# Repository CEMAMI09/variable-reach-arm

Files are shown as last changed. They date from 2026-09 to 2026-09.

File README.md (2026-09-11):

# Variable-Reach Dynamic Catching Arm

Stationary **3-DOF** manipulator with a **telescoping boom** that changes reach during interception of lightweight foam balls.

> **Engineering review B (2026-09-07): NOT a manufacturing or powered-motion release.**
> The end effector is a **three-finger grabber; no net**. The original CAD, STL files,
> motor claims and $449 budget were conceptual and are superseded where noted below.
> Complete-machine ordering remains blocked. Firmware intentionally cannot arm until
> real drivers, feedback, homing and independent stop hardware are qualified.

Current review entry points:

- `engineering/sizing.py` and `engineering/design_parameters.json`: current SI model.
- `cad/scripts/build_review_telescope.py` and `claw_gripper.py`: current parametric study.
- `cad/review_b/`: actual FreeCAD studies, geometry checks and **unpowered fit-only** STLs.
- `docs/embedded_protocol.md`: matching v2 host/MCU protocol; replaces the old v1 layout.
- `docs/review_progress.md`: accepted user corrections and review continuity.
- `docs/safety.md` and `cad/drawings/print_guide.md`: current release restrictions.

Legacy `cad/freecad/VariableReachArm.FCStd`, `cad/stl/`, old STEP and animations are
retained as historical design evidence. Do not manufacture or infer physical performance
from them. A valid CAD solid and a successful animation do not establish load paths,
assembly feasibility, motor capacity or capture success.

## Quick start

```bash
# Engineering calculations
python3 engineering/sizing.py

# Host simulation (no hardware)
python3 -m simulation.run_demo

# Plot a telemetry CSV
python3 tools/plot_run.py data/experiments/example_run.csv
```

## Docs

| Doc | Content |
|-----|---|
| [docs/requirements.md](docs/requirements.md) | Spec-derived requirements |
| [docs/architecture.md](docs/architecture.md) | Subsystems & protocol |
| [docs/safety.md](docs/safety.md) | Safety rules |
| [docs/calibration.md](docs/calibration.md) | Homing & camera calib |
| [docs/testing.md](docs/testing.md) | Test procedures |
| [docs/bringup.md](docs/bringup.md) | Bring-up order |
| [docs/integration.md](docs/integration.md) | Full integration |

## Engineering

- `engineering/calculations.md` — results & conflict resolutions
- `engineering/sizing.py` — reproducible sizing
- `engineering/bom.csv` — current itemized cost; original rows totaled $701 before reserve
- `engineering/selections.md` — why each part

## CAD

- FreeCAD assembly: `cad/freecad/VariableReachArm.FCStd`
- Parametric build: `cad/scripts/build_arm.py`
- **Printable STLs:** `cad/stl/` (regenerate via `cad/scripts/export_printables.py`)
- **Print / buy cut-list:** [`cad/drawings/print_guide.md`](cad/drawings/print_guide.md)
- Animations: `cad/animations/`

## Status

Engineering development: revised telescope/gripper studies, reproducible sizing and
protocol/planner tests. Full mechanical integration and powered hardware qualification
remain open; consult the engineering report before buying parts.

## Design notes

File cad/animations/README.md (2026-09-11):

# Current full CAD animations

Both GIFs are regenerated from `build_review_robot.py`, including the base, yaw supports, telescope, attached trunnions and three single-joint claws. The raised 850 mm shoulder with stiffened yoke is the current clearance-prototype baseline; physical qualification is pending.

- `arm_motion.gif`: prescribed yaw, pitch, full extension/retraction and claw opening/closing.
- `arm_motion_catch_fast.gif`: coordinated interception posture, closure and short retraction sequence. The old filename remains for link compatibility. There is no simulated ball capture or claim of actual motor speed.

The on-image caption is mandatory: these are kinematic demonstrations, not measured performance or proof of catch success. Playback is 12 fps; timing is illustrative. Mechanical interfaces and actuator qualification remain subject to the current engineering review.

To reproduce, run `animate_arm.animate_and_export(mode="demo")` and `animate_arm.animate_and_export(mode="catch_fast")` in FreeCAD with `cad/scripts` on its module path. Then run `python cad/scripts/make_gif.py`, and run it again with `--frames cad/animations/frames_catch_fast --out cad/animations/arm_motion_catch_fast.gif`. Pillow is required for GIF assembly. Frames are listed explicitly in `metadata.json`, so stale PNGs from earlier renders cannot silently enter a new GIF. The animation creates and closes its own temporary CAD document, and restores the previously active full assembly without saving over it.

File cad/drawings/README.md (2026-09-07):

# Fastener / bearing / shaft lists

See also `cad/drawings/print_guide.md`.

## Exploded view procedure (FreeCAD)

1. Open `cad/freecad/VariableReachArm.FCStd`.
2. Duplicate tip parts; offset CatcherFunnel +100 mm X, Guides +40 mm Z for screenshot.
3. Save image to `cad/drawings/assembly_iso.png` via FreeCAD screenshot.

## Assembly drawing notes

- Overall retracted length pitch-center → catcher ≈ 700 mm.
- Show yaw ±70°, pitch −15°/+70° travel arcs.
- Call out e-stop on base and motor bus relay.

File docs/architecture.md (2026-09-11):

# System Architecture — Variable-Reach Catching Arm

> **Review B status:** this original block diagram describes intended modules, not
> implemented capabilities. The protocol below is historical and replaced by
> `embedded_protocol.md` (v2:44-byte commands/62-byte telemetry). Motor adapters,
> true joint feedback, homing, motion execution and three-finger claw actuation are
> absent; firmware remains locked. Revised geometry/materials are in the shared
> engineering JSON. No net. No automatic throw. Read current software/electronics
> review documents for the tested implementation boundary.

## 1. Overview

```text
┌─────────────────────────────────────────────────────────────────┐
│                         HOST PC                                  │
│  vision → estimation → interception planner → trajectory cmd     │
│  simulation / logging / visualization / calibration              │
└────────────────────────────┬────────────────────────────────────┘
                             │ USB CDC / serial packet protocol
                             │ (not Wi-Fi for RT path)
┌────────────────────────────▼────────────────────────────────────┐
│                    EMBEDDED CONTROLLER (MCU)                     │
│  500–1000 Hz: PID/PD + limits + watchdog + e-stop sense          │
│  axes: yaw | pitch | extension | (latch micro-servo)             │
└───────┬──────────────────┬──────────────────┬───────────────────┘
        │                  │                  │
   ┌────▼────┐        ┌────▼────┐        ┌────▼────┐
   │ Yaw     │        │ Pitch   │        │ Ext.    │
   │ motor+  │        │ motor+  │        │ motor+  │
   │ encoder │        │ encoder │        │ encoder │
   │ belt    │        │ belt    │        │ belt    │
   └────┬────┘        └────┬────┘        └────┬────┘
        │                  │                  │
   Base + yaw         Pitch bracket     Outer boom
   bearing stack      + shaft           + inner tube
                                            │
                                      ┌─────▼─────┐
                                      │ Catcher + │
                                      │ retention │
                                      │ + sense   │
                                      └───────────┘
```

## 2. Mechanical subsystems

| Subsystem | Function | Interfaces |
|---|---|---|
| Base plate | Mount to bench; e-stop; PSU | Bolted feet; cable glands |
| Yaw stage | Rotate shoulder about Z | Motor → belt → bearing-supported turret |
| Pitch stage | Elevate boom | Motor → belt → shaft + dual bearings |
| Outer boom | Structural tube | Clamped to pitch bracket |
| Inner boom | Telescoping reach | Guides + belt clamp |
| Extension drive | \(\Delta L\) control | Proximal pulley, HTD/GT belt, idlers, hard stops |
| Catcher | Capture foam ball | Bolt pattern on inner tip |
| Retention | Keep ball after catch | Micro-servo or cable from proximal |
| Guards / stops | Safety | Mechanical travel limits |

## 3. Electronics architecture

```text
AC mains → 24V PSU → [E-STOP contactor/relay] → motor drivers (bus)
                   → MCU logic 5V/3.3V buck (always on for status)

MCU ←→ driver UART/STEP-DIR (closed-loop steppers)
MCU ←→ limit switches, e-stop sense, catch sensor
MCU ←→ USB to host
```

**E-stop:** Cuts motor DC bus independently of firmware. MCU only senses state and enters FAULT.

## 4. Software modules

### Host (`host/`)

| Package | Responsibility |
|---|---|
| `vision/` | Capture, color segment, blob center, timestamps |
| `estimation/` | Ballistic fit / KF state |
| `kinematics/` | FK, IK, workspace clamp |
| `planning/` | Reach selection, interception search, cost \(J\) |
| `trajectories/` | Quintic / trapezoidal multi-axis profiles |
| `control/` | High-level state machine, send setpoints |
| `telemetry/` | CSV logging, fault archive |
| `visualization/` | Live overlay + plots |

### Firmware (`firmware/`)

| Module | Responsibility |
|---|---|
| `motors` | Driver interface, current limits |
| `encoders` | Axis state |
| `control_loop` | Cascaded position/velocity at 1 kHz |
| `trajectory` | Execute host or local profiles |
| `safety` | Limits, watchdog, fault latch |
| `protocol` | Packet encode/decode |
| `homing` | Extension + soft zero yaw/pitch |

### Simulation (`simulation/`)

Kinematics + limits + projectile + planner for offline validation.

## 5. Communication protocol (v1)

Little-endian binary frames over USB CDC, 115200–921600 baud.

### Host → MCU command (32 bytes)

| Offset | Type | Field |
|---|---|---|
| 0 | u32 | timestamp_us |
| 4 | u8 | cmd_id |
| 5 | u8 | flags |
| 6 | i16 | yaw_mdeg |
| 8 | i16 | pitch_mdeg |
| 10 | i16 | extension_mm |
| 12 | i16 | yaw_vel_mdeg_s |
| 14 | i16 | pitch_vel_mdeg_s |
| 16 | i16 | ext_vel_mm_s |
| 18–29 | — | reserved / latch |
| 30 | u16 | crc16 |

### MCU → Host telemetry (48 bytes)

| Field | Content |
|---|---|
| timestamp, cmd_echo | sync |
| yaw/pitch/ext pos & vel | measured |
| motor currents | mA |
| status / faults | bitfield |
| catch_sensor | bool |
| crc16 | integrity |

**cmd_id examples:** ENABLE=1, DISABLE=2, SETPOINT=3, HOME=4, TRAJ=5, ESTOP_ACK=0xFF.

## 6. Control layering

```text
Vision (30–120 Hz)
  → Estimator (per detection)
    → Interception planner (10–50 Hz when ball in flight)
      → Trajectory generator (piecewise, streaming waypoints)
        → MCU setpoint stream (~100–200 Hz)
          → MCU joint PD/PID (500–1000 Hz)
```

Gain scheduling note: pitch gains may scale with \(I(L)\). Start with robust PD; add feedforward after identification.

## 7. Power & grounding

- Single-point chassis ground at base.
- Separate logic and motor returns meeting at PSU.
- Shielded encoder / USB cables where practical.
- Ferrites on motor leads if EMI affects USB.

## 8. Safety state machine

```text
BOOT → SELF_TEST → DISABLED
         ↓ enable
       IDLE (low speed caps)
         ↓ armed
       ACTIVE
         ↓ fault / e-stop / watchdog / lost host
       FAULT (motors powerless or held; latch until clear+reenable)
```

## 9. Data products

- `data/calibration/` — camera intrinsics/extrinsics, axis zero offsets.
- `data/experiments/` — CSV runs + notes linking to redesign log.
- Plots via `tools/plot_run.py`.

## 10. CAD / manufacturing interface

Parametric FreeCAD document(s) under `cad/freecad/`. Exported STEP/STL/drawings under `cad/step|stl|drawings/`. Print metadata in `cad/drawings/print_guide.md`.

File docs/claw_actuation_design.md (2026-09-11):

# Three-finger claw actuation — current prototype

Problem → a claw envelope without springs, stops or a force path cannot demonstrate
capture. Implemented → three single-pivot rigid fingers, metal M3 pivots, integral
sector stops, smooth cross-drilled M2 tendon-eye pins, fixed guide eyes, return-spring
allowances and replaceable pads. This preserves a real grabber, not a net.
Tradeoff → three spring/preload adjustments and tendon routing require calibration.

## Motion and force path

Each finger rotates from +20 degrees open to -10 degrees closed. A 12 mm-radius
horn and fixed guide at local (-25,-4.5,52) mm give about 20.91 mm free tendon span
open and 27.08 mm closed: approximately 6.18 mm take-up opens the finger.
A hypothetical 6 mm servo drum therefore needs about 59 degrees rotation, before
elasticity and adjustment allowance. The springs close; pulling the tendons opens.
The modeled spring is a 0.5 mm wire, 4.7 mm mean-diameter, two-turn envelope with
formed legs. It is not a selected spring or a verified spring-rate calculation.

For three equal tendon tensions T, drum torque must be at least 3*T*0.006/eta Nm,
plus friction, transient demand and margin. Determine T from the chosen spring's
maximum torque divided by the instantaneous perpendicular tendon moment arm.
Do not assume a 12 mm moment arm through the entire sweep. Closure time requires
finger inertia, spring torque, contact compliance and friction measurements.

The tendon eye is a 1 mm transverse bore through the smooth 2 mm pin; edges need
rounding/polishing to prevent line abrasion. The fixed eye is an allowance that
requires a low-friction liner. Metal pivot spacers/washers isolate clamp preload
from the rotating finger. Do not clamp a printed finger between bolt head and nut.

## What is still incomplete

The modeled tendons currently terminate at the fixed guide eyes. A complete
three-line equalizer, housing retention, Bowden route and actual servo horn/drum
are NOT modeled or released. The user's servo model and shaft/mount dimensions
are unknown. A generic servo envelope must not be treated as a compatible part.
Select spring torque and tendon termination together with that servo; test release,
retention and response before using captured objects. Servo current and a separate
regulated supply must also be measured/qualified.

Print fingers and palm initially for fit in PETG, laid to keep bending loads in the
layer plane, typically 5–6 perimeters and 30–40% infill. Qualify the final material
at actual temperature/load; use tough nylon or ASA only when justified by testing.
TPU belongs on replaceable contact pads, not the entire load-bearing finger.
Use steel pivots, real springs and smooth purchased line guides/liners.

Verify free rotation at both stops, spring-leg retention, tendon rub through every
pose, captured-ball retention and power-loss behavior. A closed claw is not proof
of impact absorption or successful catching. No powered throwing release is approved.

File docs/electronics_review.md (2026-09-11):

# Electronics, embedded and power engineering review B

Review date: 2026-09-07. Status: **not ready to order the complete electronics or run
high-speed hardware**. Keep Teensy 4.1 as a capable commissioning controller if already
owned; its compute capacity is not the bottleneck. The old repository described
driver, encoder, homing and safety features that were not implemented.

## Problems, consequences and implemented response

1. **Signed int16 millidegrees overflow at ±32.767 degrees.** Valid ±70 degree poses
   and intended rates failed packing or wrapped telemetry. Replaced with matching
   v2 32-bit command/telemetry fields, static size checks and cross-language tests.
   Tradeoff: larger frames, insignificant at 100 Hz USB telemetry.
2. **Invalid CRC refreshed the watchdog and stream had no recovery framing.**
   Damaged/replayed bytes could appear alive. Added header/version/size/CRC validation,
   sequence checks, bounded resynchronization and inter-byte expiry. Tradeoff:
   corrupted commands latch faults and require diagnosis instead of silent retry.
3. **No drivers/feedback/homing were implemented; fabricated zero looked plausible.**
   Motion now remains under a permanent unqualified fault, telemetry uses explicit
   missing sentinels, unsupported claw/home/trajectory commands reject, and no servo
   output is configured. Tradeoff: honest logic-only release until real adapters exist.
4. **E-stop sensing missed broken wires; software watchdog was unused.**
   Added NC/open-wire sense interpretation and timing diagnostics. A recovered-loop
   diagnostic cannot interrupt a hung MCU; a hardwired stop and independent watchdog
   remain mandatory. Tradeoff: additional verified hardware and cost.
5. **Arbitrary huge gains saturated a normalized output for tiny angular errors.**
   Replaced presumed tuning with zero gains, finite checks, reset and anti-windup.
   This controller is a tested mathematical scaffold, not a motor controller selection.
6. **Three-finger claw was represented by an unverified latch bit.**
   No automatic actuation remains. Select an actuator against closure-time, force,
   travel, stall-current and feedback requirements; qualify aperture and retention.
   Preserve the actual three-finger mechanism, with actuation proximal where feasible.

## Motor/driver decisions

MKS SERVO42C is a candidate board, not a verified motor operating envelope. Its maker
lists 7–28 V operation, current setting up to 3 A and maximum 1000 rpm.
At 36 teeth × 2 mm pitch, 1.2 m/s requires 1000 rpm: there is no speed reserve and
loaded torque is unproven. 1.5 m/s would require 1250 rpm and exceeds that published
limit. Do not substitute holding torque for torque at speed. Verify exact motor,
board revision, firmware version, bus voltage and torque-speed curve before buying.
[Makerbase SERVO42C documentation](https://github.com/makerbase-mks/MKS-SERVO42C).

The old SERVO57C-or-equivalent item is not a sufficiently exact electrical interface.
Choose one exact board/motor combination and archive its manual, torque-speed curve,
current definition (peak/RMS), command protocol, feedback update timing, fault output
and safe-disable behavior. Changing between C/D revisions is not a drop-in software
decision. A closed-loop motor encoder does not detect belt slip, output-shaft damage
or telescoping belt/clamp movement. Provide joint reference and a defensible output
feedback/following-error strategy before releasing autonomous motion.

Prefer timer-generated STEP/DIR into the drive's inner current/position loop if its
interface is qualified. Do not assume a normalized MCU duty value maps to that
interface. Vendor UART may be sufficient for telemetry only after measuring aggregate
poll latency; three axes with sequential blocking transactions are not automatically
a 1 kHz feedback path. Record encoder age, packet counters, following error and faults.

## Power calculation and simultaneous motion

The reproducible screen in `engineering/review_sizing.py` and its generated
`engineering/review_results.json` currently bounds simultaneous mechanical power at
approximately93.19W, assumes65% conversion efficiency,40W major-motor copper loss,
35W extension/driver loss and15W logic, giving approximately233.36W /24V =9.72A.
These are assumption-based procurement screens, not measured current. At 25% reserve
the arithmetic minimum is12.15A, before ambient derating and verified surge/inrush.

Do not sum motor phase-current labels to estimate bus current. For each phase,
copper loss is I_RMS² R; sum actual phases, winding temperature dependence, iron loss,
driver switching/conduction loss and mechanical power, then divide by bus voltage.
Calculate RMS current over the real duty cycle; holding and failed-catch retries can
dominate heating even if average mechanical work is low. Measure peak current on all
axes accelerating together, RMS over repeated trials, supply droop and driver case
temperature. There is no measured continuous thermal envelope yet.

LRS-350-24 remains a possible 24 V supply if enclosure/thermal/AC integration is
appropriate; use its exact model rating and derating curves, not a generic 15 A label.
Its source-current/overvoltage protection is not a regenerative sink specification.
[Mean Well LRS-350 data sheet](https://www.meanwell.com/Upload/PDF/LRS-350/LRS-350-SPEC.PDF).

The revised mechanical screen estimates about8.35J of recoverable stopping/gravity
energy. For an isolated 4700 microfarad bus starting at 24 V,
V_final = sqrt(24² + 2E/C) = approximately64.27V if all of it reaches the capacitor.
This is far above a 28 V-rated drive. Even 10 J would require about 0.096 F just to
stay between 24 and 28 V. A small capacitor or arbitrary TVS is not a braking system.

Select a shunt clamp/dump with documented threshold/tolerance, pulse energy, repetitive
thermal rating and bus-voltage overshoot below the **lowest** drive rating. Keep it
on the driver side of the stop contactor. A 24 V nominal / 28 V maximum driver leaves
a tight tolerance budget; this remains a purchase/design gate. Use a higher-voltage
rated compatible drive or a lower qualified bus only after recalculating motor speed
and clamp behavior. Bulk capacitance also increases contactor inrush.

## Wiring and interfaces

- Teensy GPIO and ADC accept 0–3.3 V and are not 5 V tolerant. Level-shift any 5 V
  encoder/fault interfaces and verify opto-input current/thresholds. Avoid simultaneous
  external VIN and USB power unless the documented VUSB/VIN isolation is performed.
  Keep a separate gripper supply if its transients can reset logic.
  [PJRC Teensy 4.1 electrical documentation](https://www.pjrc.com/store/teensy41.html).
- Use an enclosed mains inlet/supply with protective earth, fuse, strain relief,
  finger-safe terminals and a deliberate disconnect. Printed electronics covers can
  guard low-voltage access; they do not establish a rated mains enclosure.
- Prototype a short16AWG copper trunk for the screened9.72A bus and12.15A reserve
  requirement; qualify
  actual insulation, routing, bundle heating and connector ratings. At 13.2 mOhm/m
  nominal copper resistance, a 2 m total loop at 10 A drops 0.264 V and dissipates
  2.64 W. This is a resistance estimate, not an ampacity certificate.
- Use separately fused branches sized to each conductor and connector. Fuse ratings
  require time/current curves, fault available current and measured inrush. Do not
  treat a fuse as software current control or use unverified Dupont connectors for
  motor power. Locking connectors, keyed pinouts and ferrules where specified.
- Run twisted motor pairs; separate motor wires from encoder/limit wiring. Shield
  according to driver guidance, bond chassis/PE deliberately, keep power returns out
  of logic signal paths. Test USB disconnect immunity while reversing all axes.
- NC switch loops use 3.3 V pullups with filtering/Schmitt inputs appropriate to wire
  length. Their polarity is now explicit in firmware; homing needs bounded debounce
  and fault detection without delaying the hardware E-stop chain.
- Budget real cable flex loops through full yaw, pitch and telescope travel. Add
  strain relief at both stationary and moving ends; verify wire bend radius and
  keep the claw cable out of moving guides and belt teeth.

## Required additions and decisions before purchasing

Price the DC-rated stop/manual-reset chain, independent enable/watchdog, pitch brake
or restraint, regenerative dump, individual fuses/holders, mains enclosure/PE,
locking connectors/level shifting and real gripper actuator/feedback. These are
essential functions, not optional budget cuts. Reuse an owned MCU/PSU/camera only
after checking ratings; stage the single-axis rig before buying all three drives.

Open design work: exact wiring schematic and connector/pin map; driver/encoder
adapters; current channel/thresholds; homing; stop/brake interface; gripper actuation;
bus clamp selection. Prototype measurements: torque-speed and duty temperature,
current/droop/regen waveforms, EMI and timeout behavior, feedback latency and claw
closure/retention. Electronics readiness score: 4/10; embedded motion readiness:
3/10. The safety/protocol scaffold is useful but these scores must not imply a
qualified electromechanical system.

## Build evidence

The root review task successfully compiled the actual Teensy target with
`pio run -d firmware` on2026-09-07 (reported61.90s). No hardware was flashed.
This verifies the current target build in addition to host-side protocol/control
tests; it does not establish driver interfaces, timing under physical I/O load,
encoder accuracy, brake action or a qualified motion system. Permanent unqualified
motion gating remains appropriate until those hardware functions are implemented
and tested.

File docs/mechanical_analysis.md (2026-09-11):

# Mechanical design, fabrication and physical acceptance

This report covers RevB's telescope and three-finger claw concept. It supersedes the
original unsupported claim of manufacturability and does not release the full robot
for high-speed use. The live CAD study and `engineering/design_parameters.json`
are the geometry references. The complete yaw/pitch transmissions, brake, hard-stop
mounts and detailed electronics still need procurement dimensions and assembly CAD.

## Changes and tradeoffs

1. **Original problem:** round tubes and disconnected guides supplied no credible
anti-rotation or complete sliding load path. **Why it matters:** twist and binding
destroy repeatability and interception. **Implemented:** square purchased aluminum
outer/inner tube study, moving rear shoes and fixed mouth shoes with190mm minimum
spacing/240mm overlap. **Tradeoff:** more mass than high-grade CF, but predictable
isotropic properties, common stock, simple cuts and no drilled composite joints.
The4.7625mm nominal gap permits the belt/clamp; a larger inner tube would be stiffer
but leaves insufficient belt packaging. Do not add a second guide rail by default.

2. **Original problem:** geometry allowed catcher mounting hardware to intersect the
outer at retraction; a through pitch shaft would block the inner. **Implemented:**
outer ends at520mm, the inner now extends to585mm at retraction and the claw clamp
was shifted25mm forward to clear the idler/belt envelope, with revised rear support and separate
external trunnions. **Tradeoff:** rear swing envelope extends to roughly300mm behind
pitch with motor/belt guards. Check this envelope across every yaw/pitch position.

3. **Original problem:** motors were approved using holding torque and a nonexistent
45% balance spring. **Implemented:** reproducible translated-mass dynamics, I_dot,
cross-axis coupling, dynamic guide loads and honest motor requirements. No balance
credit. **Tradeoff:** maximum-speed procurement remains blocked until a measured or
readable exact manufacturer curve is obtained; slower restrained tests are feasible
with a separately qualified drive. This is better use of money than buying the wrong
three motors and compensating with increasingly heavy mechanisms.

4. **Original problem:** passive capture and active retraction had no force budget.
**Implemented:** three curved claws, single servo opening via three tendons, spring
closure concept, TPU pads, steel pivots; force/energy screens at1/2/4m/s relative speed
and signed radial matching. **Tradeoff:** no net, as required by the user; shorter
compliance travel demands much better velocity matching. The servo/tendon routes,
spring rates, retention geometry and stop strength are concept-level until assembled.

5. **Original problem:** sparse BOM understated the bill by$252. **Implemented:**
exact quantity arithmetic, full-spool/stock purchase cost, reduction hardware, brake,
dump, fusing, feedback, guards, harness and reserve. **Tradeoff:** complete cost is
above budget. A restrained single-axis rig is the cost-efficient next purchase.

## Print, fabricate or buy decisions

The settings below are starting **process specifications**, not material strength
certificates. Use a0.4mm nozzle/0.2mm layers unless calibrated otherwise. Continuous
walls/ribs carry load; infill fills space. Structural print proof coupons must use
the same machine, material dryness, orientation, layer height and temperatures.

- **Fixed front guide housing — can be printed if designed correctly.** ASA for
temperature-stable indoor parts, or PETG for first low-speed coupons. Print the split
faces flat so band-clamp compression and bolt load lie mainly in the XY plane.
Use6 perimeters (nominal2.4mm shell),35–45% gyroid,4–5mm ribs and >=3mm fillets.
Nominal housing bore must be fit to measured38.1mm outer stock; do not force a printed
press fit. Use two metal band clamps or M4 through-bolts with captive nuts and broad
washers; heat-set inserts serve covers/adjusters only, not the primary restraint.
Failures: creep preload loss, layer splitting beside clamp ears and pad migration.

- **Moving rear guide carrier — can be printed if designed correctly.** Tough dry
nylon is preferred if the printer can reliably dry/enclose it; PETG is acceptable for
restrained low-speed testing. Print split clamp halves flat,6–8 perimeters and40%
infill,>=3mm webs. The total radial gap4.7625mm must accommodate rigid carrier,
wear pad and running clearance; do not fill this entire gap with soft UHMW tape.
Use replaceable0.5–1mm acetal/UHMW wear faces backed by rigid shims and30mm axial
contact. Top faces around the belt/clamp can be much narrower than the side faces;
the pressure model conservatively uses2.5mm individual-face width until final CAD
contact width is reconciled. Actual corner radii must clear. Captive M3 nuts and
steel clamp plates distribute load. Failures: pad edge wear, swollen nylon, loose
fasteners, carrier creep and binding from excessive four-sided preload.

- **Pitch tube clamp and trunnion carrier — can be printed for bench iteration;
hybrid construction required for high dynamics.** ASA or tested nylon, split faces
flat,8 perimeters,40–50% infill,>=5mm ribs and >=4mm stress-transition radii. The
metal trunnions must have broad bolted flanges or crossbars that carry shaft reaction
through metal hardware into circumferential tube clamps. Use M4/M5 through-bolts,
large washers and locknuts; keep threads/inserts outside tensile peel load paths.
Critical dimensions are12mm shaft support, tube clearance, trunnion coaxiality and
opposed bearing positions. Failures: clamp slip, layer peel, thermal creep, cracked
bolt ears, thin-wall tube crushing. The desk tube stress factor does not approve this
printed component. Local coupon and subassembly proof tests are mandatory.

- **Yaw frame/bearing carriers — can be printed if metal loads bypass weak joints.**
Print ASA bearing blocks with split bores facing up,8 perimeters,40% infill and>=5mm
base ribs. Bore sizing comes from calibrated coupons for actual bearing OD; clamp
around the outer race with a stop gap, never hammer a press fit. Use metal shaft,
real bearings, spacers/collars and M5 through-bolts into the anchored frame.
Avoid large tall printed columns; use low triangulated stock frame. Failures: yaw
wobble from bearing separation too small, bearing creep and unanchored base overturn.

- **Motor brackets — can be printed for mockup; should probably be sheet/angle
metal for powered duty.** Motors concentrate heat and belt preload. Use common
3–4mm aluminum angle/plate drilled with a printed jig; low mass is maintained by
triangulation. If printed for the bench, ASA6–8 perimeters/40% infill, flange down,
M4 through-bolts and a metal spreading plate. Set motor clearance from the *selected*
part drawing, not a generic NEMA cube. Failures: slotted tension mount slips,
plate flex and thermal creep changing belt alignment. Do not bond motor mounts.

- **Large reduction pulley — can be printed after qualification.** ASA or tough
nylon, shaft axis vertical,6–8 perimeters and40–50% infill, solid tooth perimeter
region but ribbed web, metal split-clamp hub and through-bolted pattern. Measure
pitch diameter/runout and confirm vendor-compatible tooth profile. No set screw
cut directly into plastic; no unsupported printed motor pinion. Failures: tooth
shear, layer splitting at hub, creep, belt ratcheting and eccentricity. Treat it as a
replaceable wear part, and do not route the only gravity-fall restraint through it.

- **Small pulleys, idlers, bearings, shafts and pivot pins — should definitely not
be printed.** Buy metal timing pulleys with compatible belts, ball bearings and steel
shafts/pins. A smooth printed cylinder is not a timing pulley. M3 steel shoulder
pins/bolts with smooth bearing surface and positive retention serve claw hinges;
do not rotate on screw threads. Side-loads require spacers and washers.

- **Telescope tubes — should definitely not be printed.** Buy aluminum stock with
certified alloy/temper where possible. FDM seams, creep and poor stiffness per mass
are incompatible with a long sliding structural member. CF could lower boom mass
later, but laminate axial/torsional stiffness, corners, abrasion and fastening need
supplier data and end sleeves. CF-filled filament is not equivalent to a CF tube.
Do not cut a long belt slot into either tube; it reduces torsion stiffness and invites
crack growth. The belt/clamp occupies the annular space instead.

- **Claw carrier and rigid fingers — should be printed.** Tough PETG/ASA or dry
nylon for rigid load-bearing fingers,6 perimeters and30–40% infill with solid hinge
regions. Print each curved finger flat on its broad side so the primary finger-root
bending path lies in the XY plane. Use >=3mm fillets and >=3mm ligaments around
M3 pin holes, with smooth replaceable sleeves/washers. Drill/ream calibrated holes;
do not force pins. The common carrier can use4–6 perimeters/30% infill with metal
clamping hardware. Constrain each jaw with mechanical open/closed stops so the
servo never serves as the hard stop. Failures: hinge-root crack, pin walkout, tendon
abrasion, spring escape, overcenter jamming and finger fatigue.

- **Claw contact pads/compliant inserts — should be printed.** TPU95A, broad contact
face down where possible,3–4 perimeters and10–20% infill,2–3mm walls. Mechanically
trap pads using dovetail/through-hole features plus removable screws; do not rely
only on adhesive. Pad thickness/stroke comes from instrumented foam-ball impact
coupons. The25mm effective stop distance remains unverified. TPU on aluminum/rigid
plastic needs rounded transitions. Failures: tear, bottoming-out, rebound/bounce-out
and creep that changes retention aperture.

- **Tendons, springs, hard stops and critical brake parts — should definitely not
be printed.** Use rated cord/cable, metal torsion springs with captured legs, metal
end-stop strap/screws and a specified brake. Print guards and fixtures around them.
A spring fractured/ejected toward the user is a hazard; enclose it. Printed flexures
are useful compliance coupons, not an unmeasured permanent retention spring.

- **Cable clips, sensor mounts, covers and wire strain relief — should be printed.**
PETG/ASA, broad base flat,3–4 perimeters/15–25% infill,>=2mm wall; M3 inserts are
appropriate here. TPU boots can use3 perimeters/15% infill. Provide tie points on
both sides of connectors, protected flex loops, service labels and removable covers.
Do not run wiring under belt teeth or allow free loops inside the telescope.

- **Base, frame, guards — should probably be stock material.** Rigid bench anchor,
plywood/metal base and aluminum angle avoid printing kilograms. Use metal through
fasteners and triangulation. Transparent containment uses appropriate polycarbonate
sheet/frame; printed edging is fine. Guard adequacy must be evaluated for thrown
balls and failed moving components, not only finger access.

PLA/PLA+ may make dimensional jigs and cold fit-check mockups. Its low-temperature
creep is a poor reason to retain it for hot motor mounts. PETG trades toughness and
ease for creep; ASA adds thermal margin but needs printing control; nylon adds
toughness but changes with moisture. Fiber-filled nylon may improve stiffness and
dimensional stability, but abrasion, layer strength, notch behavior and hardware
compatibility still require coupon testing. None deserves automatic structural credit.

## Assembly and maintenance sequence

1. Measure stock straightness, wall, corner radii and bore. Cut square, deburr and
clean; retain offcuts for fit/fastener coupons. Do not sand aggressively to force fit.
2. Assemble bare inner/outer shoes on the bench with no motor. Adjust one datum pair
and the orthogonal compliant/shimmed pair; check push force and yaw/twist at each
50mm station. Record forward/reverse breakaway and moving friction under tip load.
3. Fit the rear carriage and belt endpoints before fitting removable rear drive
supports. Verify the metal clamp passes every guide and leaves the top belt corridor.
4. Install belt pulleys/tensioner, end stops and switches. Use a thinmetal top strap
secured by two bands for stop threads, not thin-tube-wall threads. Keep stop tips out
of the moving belt strip. Hand-cycle to both physical stops. Confirm software500mm
endpoint is before the proposed515mm hard stop with enough measured braking distance.
5. Assemble claws/pins/springs/tendons/servo while detached, weigh whole tip and test
all jaw angles. Check passive retention in arbitrary orientation and release repeatability.
6. Install in a clamped extension rig behind a guard. Commission at lower than the
proposed150mm/s cap initially. Check independent current/limit/E-stop responses.
7. Build and independently proof the yaw/pitch support, drive and brake before
adding the telescope. Verify power-off drop behavior with a restraint attached.
8. Mount the telescope/claw, route strain-relieved harness, log unloaded/loaded current
and mass, then increase operating limits only after the explicit test gates pass.

Keep guide shoes, fingers, pads and belts accessible and individually replaceable.
Use standard hex hardware with tool access from outside the motion envelope. Do not
bury sensor connectors behind glued shells. Recheck pad preload and belt tension
after the first50,500 and5000 cycles, recording wear and any rising friction.

## Hard-stop and claw timing screen

`review_results.json` contains extension stop energy, equivalent rotor mass and a
two-M4grade8.8-screw screen. The model assumes5mm effective bumper travel,2× average
deceleration load and continued pushing equivalent to0.6Nm extension motor torque.
This is intentionally more demanding than inertial energy alone. Actual motor stall
force/current cutoff, metal strap bending, clamp slip, screw engagement and inner
wall crushing remain release gates. Both screws need load-sharing contact tolerances;
one-first-contact case should also be proof-tested. Metal screw strength does not
prove the thin tube or carrier survives. Do not use bare sharp screw points as impact
faces; spread contact and fit elastomer bumpers with a metal secondary stop.

Numerically the synchronized target-speed example is0.451J and233N illustrative
design load. Two M4 root3.1mm screws with **maximum3mm unsupported length** give
about122MPa equivalent stress and5.23 nominal yield factor at640MPa. If one screw
takes the entire event, that factor falls to about2.61 before further impact
uncertainty. The3mm maximum replaced an inadequate5mm lever after critique.
Maintain this support distance and design the metal strap and bumper for the
single-contact event. This remains a screen, not a released target-speed safeguard.
Low-speed rig operation reduces kinetic energy substantially but still includes
motor-driven pushing. The complete claw now carries a170g weighing allowance
including servo/hardware/wiring; the CAD plastic volume alone is not its mass.

The illustrative claw calculation models18g110mm finger plus4g pad,0.015Nm spring
and0.005Nm friction. It predicts about104ms no-contact closure, while a ball crosses
60mm at4m/s in15ms. Those values are not measured spring specifications, but they
show why contact-triggered closure cannot be assumed. Three tendons require an
illustrative0.10Nm servo opening torque with2× margin at10mm servo horn/12mm finger
horn. Servo speed, horn sweep, tendon take-up, current spike and simultaneous jaw
opening must be measured. Spring force must retain the ball without ejecting it or
causing excessive contact pressure. Use a predicted preposition and passive yielding
capture geometry; do not certify retention from animation alone.

## Desk-design gates versus prototype unknowns

Still solvable before ordering: selected motor/driver torque-speed curves, exact
reduction CAD, brake and DC stop topology, final belt working ratings, hub fastening,
shaft/bearing layout, camera synchronization choice and the cost/requirements decision.
Do not call these physical unknowns to conceal unfinished design.

Physical unknowns after those decisions: as-built guide friction/creep and tube fit,
claw/foam impulse and rebound, true tip mass/stiffness, tendon closure timing,
loaded acceleration/thermal behavior, encoder repeatability, loop stability, vibration,
vision latency and catch success. Test the tube/guide/claw parts first, because those
are cheap to change and determine whether the high-speed ambition is credible.

Likely first failures are finger hinge/pad retention, rear-guide wear/preload drift,
belt clamp slip or tooth skipping, tendon abrasion and printed motor-mount creep.
Contain and instrument those failures during low-energy tests. The design is suitable
for **fit coupons and restrained subsystem experimentation**, not a final manufacturing
release or an autonomous catching build.

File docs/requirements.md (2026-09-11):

# Requirements — Variable-Reach Dynamic Catching Arm

**Project:** Stationary 3-DOF high-speed manipulator with dynamically telescoping reach for intercepting lightweight foam balls, with stretch goals for throwing.

**Document status:** Derived from project specification. Conflicts with budget or physics are resolved in `engineering/calculations.md`.

**Review B override, 2026-09-07:** these speeds are aspirational design requirements,
not certified operating limits. Geometry now comes from `engineering/design_parameters.json`.
User requires an actual claw/finger grabber, **no net**. The capture plane and approach
direction must be calibrated. A3-DOF straight arm has a minimum-radius exclusion zone;
targets inside it are not made reachable by projecting them to the retracted radius.

---

## 1. Objective

Build a purpose-built catching robot that can:

1. Detect a thrown lightweight foam ball.
2. Predict its trajectory.
3. Move to an interception point.
4. **Change physical reach while moving** when the interception point exceeds normal reach.
5. Catch and retain the ball.
6. Eventually throw toward a specified target.

Central capability: **dynamic morphology as part of interception planning** — extend only as far as necessary; remain retracted when possible (lighter, stiffer, faster).

### Non-goals (v1)

- Generic industrial 6-DOF arm.
- Anthropomorphic elbow or multi-axis wrist.
- Humanoid multi-finger hand.
- Hard projectiles (baseballs, metal, rocks).
- Reinforcement learning as first control approach.
- Separate flywheel launcher for throwing.

---

## 2. Kinematic architecture

```
Fixed base → yaw → pitch → variable-length telescoping boom → lightweight catcher
```

| DOF | Axis | Notes |
|-----|---|---|
| 1 | Shoulder yaw | Vertical axis, bearing-supported |
| 2 | Shoulder pitch | Highest torque axis |
| 3 | Linear extension | Single active telescoping stage |

Configuration: \( q = [\theta_y, \theta_p, L] \)

---

## 3. Geometry

| Parameter | Min | Target | Max | Unit |
|---|-----|---|-----|---|
| Base footprint | — | ≤350×350 | 350×350 | mm |
| Pivot height \(h\) | 850 | **850** | 900 | mm |
| Retracted reach \(L_{\min}\) | 650 | **700** | 750 | mm |
| Extended reach \(L_{\max}\) | 1100 | **1200** | 1250 | mm |
| Extension stroke \(\Delta L\) | — | **500** | — | mm |
| Min telescoping overlap | 180 | 200 | 250 | mm |

### Workspace

| Axis | Range |
|---|---|
| Yaw \(\theta_y\) | \(-70^\circ \leq \theta_y \leq +70^\circ\) (min total 140°) |
| Pitch \(\theta_p\) | \(-15^\circ \leq \theta_p \leq +70^\circ\) |

Software limits must prevent boom contact with floor, base, frame, operators, or electronics. Primary workspace: forward hemisphere.

### Forward kinematics (world frame)

\[
x = L\cos(\theta_p)\cos(\theta_y),\quad
y = L\cos(\theta_p)\sin(\theta_y),\quad
z = h + L\sin(\theta_p)
\]

Inverse: \( L = \sqrt{x^2+y^2+(z-h)^2} \) with appropriate \(\theta_y,\theta_p\). Reject workspace violations; never silently clamp an interception target.

---

## 4. Target object

| Spec | Value |
|---|---|
| Type | Lightweight foam ball |
| Diameter | 60–80 mm (preferred ~70 mm) |
| Mass | 20–80 g (hard max 100 g) |
| Incoming speed | 2–4 m/s initial; stretch 5–6 m/s |

---

## 5. Performance

### Static / positioning

| Metric | Target |
|---|---|
| Yaw repeatability | ≤ ±1° |
| Pitch repeatability | ≤ ±1° |
| Extension repeatability | ≤ ±10 mm |
| End-effector static error | < 25 mm over most workspace |
| Tip deflection at \(L_{\max}\) | < 25 mm under normal static loading |

### Dynamic

| Metric | Minimum | Target |
|---|---|---|
| Extension speed | 0.8 m/s | 1.2–1.5 m/s |
| Extension acceleration | — | 3–5 m/s² |
| Yaw / pitch angular velocity | — | 100–150 °/s |

Initial software limits must be considerably lower (~40% of design targets).

### Mass

| Item | Target |
|---|---|
| Catcher | < 150 g |
| Catcher + tip sensors | < 180 g |
| Major motors | Near base / yaw / pitch — **not** on extending tube |

Structural safety factor ≈ 2.5× static. Drivetrain torque margin ≈ 2× where practical.

---

## 6. Mechanical subsystems

### Telescoping boom

- Single active stage (outer tube + inner sliding tube).
- Replaceable low-friction guides (≥2 widely spaced regions).
- Materials: carbon fiber and/or thin-wall aluminum primary structure; 3D print for guides, mounts, catcher, brackets.
- Both extension and retraction actively driven (no gravity/spring-only return).

### Extension drive (selection by calculation)

Preferred candidates:

- **Option A:** Timing-belt-driven telescope (proximal motor).
- **Option B:** Dyneema / high-strength cable capstan (proximal motor).

Lead screw only if calculations prove dynamics are met (expected rejection for speed).

### Yaw

Rigid base attachment, bearing radial+axial support, closed-loop encoder, preferred belt reduction, hard stops / clearance, software limits. No unsupported motor-shaft cantilever of the full assembly.

### Pitch

Sized with \( \tau = I\alpha + \tau_g + \tau_f \). Controller must know \(L\) because \(I = I(L)\). Optional counterbalance only if it does not harm dynamics.

### End effector

Forgiving capture: three mechanically connected single-joint fingers with compliant contact pads and positive retention. No net or fabric pocket. Opening/closing actuation and passive compliance must be tested with the specified ball.

| Spec | Value |
|---|---|
| Entrance diameter | 120–150 mm |
| Depth | 100–150 mm |
| Retention | Compliant gate / micro-servo / cable latch (lightweight) |
| Capture confirm | IR break-beam, switch, Hall, FSR, etc. |

Active impact absorption (stretch): controlled short retraction after capture to reduce \(v_{rel}\).

---

## 7. Electronics & sensing

### Required feedback

- Yaw position (encoder)
- Pitch position (encoder)
- Extension position (motor encoder and/or linear/string encoder)
- Homing / limit switches on extension
- Hardware e-stop cutting motor power independent of software

### Recommended / optional

Motor current; boom strain; catch force; tip acceleration.

### Control split

| Layer | Role | Loop rate |
|---|---|---|
| Embedded MCU | Motors, encoders, safety, trajectories, watchdog, telemetry | 500–1000 Hz |
| Host PC | Vision, estimation, planning, logging, visualization | Best-effort |

Wired link only for hard real-time path (USB CDC / serial / CAN / Ethernet). No Wi-Fi for motor control.

Budget: **hard max $500**; preferred **$300–450**; ≥10–15% reserve.

---

## 8. Perception & planning

### Vision phases

1. Manual commands only.
2. Single-camera planar tracking.
3. Stereo 3D (preferred ≥60 FPS, target 120 FPS; latency > resolution).

### Ball state

\[
\mathbf{x} = [x,y,z,v_x,v_y,v_z]
\]

Ballistic model initially; drag optional. Estimator: LS fit / KF / EKF.

### Reach selection

- If \(L_{req} \le L_{normal}\): remain retracted only if the ball is inside the calibrated gripper capture volume; otherwise search a future reachable crossing or reject.
- If \(L_{normal} < L_{req} \le L_{max}\): extend only to the required capture plane. A positive radial margin is allowed only within a measured capture depth; it must not displace the grabber away from the ball.
- If \(L_{req} > L_{max}\): unreachable.

### Interception

Search future times \(t_i\); valid only if workspace + actuator limits allow arrival. Minimize configurable cost \(J\) (time, extension, accel, velocity penalties).

### Trajectories

Smooth profiles (trapezoid / S-curve / quintic). No step position jumps. Simultaneous multi-axis motion when beneficial.

---

## 9. Safety & faults

Mandatory: hardware e-stop, current limits, travel limits, watchdog, encoder fault detection, software velocity caps, startup verification, low-speed homing, mechanical extension stops, lightweight foam only, optional barrier for high-speed tests.

Disable high-speed motion on: invalid encoders, unexpected limit, watchdog, lost comms, overcurrent, extension out of range, illegal trajectory. Log fault reason.

---

## 10. Telemetry & testing

Log CSV-exportable: axis positions/targets/velocities, currents, predicted/measured ball state, interception point, catch result.

Quantitative tests required for positioning, dynamics, structure, vision, catching, and impact (see `docs/testing.md`).

### Initial success bar (≈8 weeks)

Autonomous homing, 3-axis position control, rapid extension, ball track + predict, reach decision, catch slow–moderate underhand throws. Target ≈**70%** catch success in a defined test volume — or document measured rate honestly.

### Defining demo

- **A:** Catch inside normal reach without extending.
- **B:** Catch beyond normal reach with dynamic extension.
- **C:** Catch and return / throw (stretch).

---

## 11. Software & CAD deliverables

Repository layout per architecture doc. FreeCAD parametric model with listed parameters. Calculations before frozen mounts. Modular host + firmware. Simulation before autonomous physical intercepts.

### Development order (control)

Manual low-speed → homing → position → velocity → accel → multi-axis → tracking → dynamic extension → vision pose → intercept → velocity-matched catch → throw.

### Milestones

M0 calculations/BOM → M1 extension rig → M2 yaw/pitch → M3 integrate telescope → M4 trajectories → M5 track ball → M6 predict → M7 intercept no contact → M8 drop catch → M9 toss catch → M10 reach decision demo → M11 impact absorption → M12 throwing.

---

## 12. Design priorities

1. Function  
2. Safety  
3. Dynamic performance  
4. Low distal mass  
5. Stiffness  
6. Serviceability  
7. Measurability  
8. Iteration ease  
9. Cost  
10. Appearance  

Visible engineering preferred over decorative panels. Modular subsystems; expect failures and document redesign loops.

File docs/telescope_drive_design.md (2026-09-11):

# Telescope drive detail — current prototype

Problem → belt ends, motor support and end stops lacked a credible load path.
Why it matters → an attractive telescope could slip, jam or eject its inner tube.
Implemented → rear plug and bolted belt clamp, supported front idler, common-bolt
motor bracket, split stop collars, smooth steel pins and keyed replaceable TPU pads.
Tradeoff → additional hardware and moving mass; these are qualification prototypes.

## Geometry and assembly

The current single sliding tube travels 500 mm. Nominal guide spacing is 690 mm
retracted and 190 mm extended; tube overlap is 740 and 240 mm respectively.
The rear plug is 32 mm long and nominally 22.025 mm square inside the 22.225 mm
bore. Measure actual corner radii, straightness and extrusion size before printing.
Two recessed M3 bolts retain it; its relief channels clear the guide fasteners.
A 26 x 24 x 2.2 mm metal clamp cap and four M2 screws trap the two open-belt ends.
The clamp model compresses the belt from 1.38 to 1.20 mm locally. This is an
allowance, not a qualified tooth profile or verified gripping preload.

The extension motor faceplate shares two M4 bolts and metal compression spacers
with the rear stop collar. At the front, a split outer-tube collar supports a
bridged idler bracket. Two purchased 625 bearings (5 x 16 x 5 mm), a ground 5 mm
shaft, inner-race spacers, metal caps and shaft collars support the metal pulley.
The collar can be manually shifted approximately +/-2 mm before clamping to set
belt tension; clearance over that adjustment and actual preload remain to be tested.
Do not tension by bending the bearing support. Install cap nuts before the pulley.

Install guide nuts and rear plug first, thread and clamp the belt ends, fit the
inner tube, assemble the idler bearings and pulley, set both stops, then tension
with the front collar. Check full travel by hand before attaching motor power.
Mark collar locations to detect slip. Caps and belt-clamp screws must remain
accessible without separating the entire arm from its base.

## Stops and independent load screen

Four 5 mm steel pins project into the outer-tube corner corridors at z=12 mm,
above the side guide pads. Pins are retained by steel caps; no threads are cut
into the thin tube wall. The nominal soft-contact/hard-contact positions are
-2/-5 mm and 501.5/504.5 mm. Normal commanded travel remains 0–500 mm.
The maximum hard-stop position still leaves 185.5 mm guide spacing.

`engineering.review_sizing.extension_hardstop_screen` uses current effective
slider mass including reflected extension motor inertia. It checks one pin taking
first contact, 4 mm unsupported length, a 3 mm assumed stopping stroke and an
illustrative twice-mean impact force plus motor force. It assumes only 250 MPa
steel yield. The 3 mm pad thickness is NOT evidence of 3 mm usable stopping stroke.
A real pulse can exceed this screen. Printed lug bending, collar axial slip,
tube bearing, TPU compression and pin grade must be proven separately.

The CAD mass screen estimates 55 g for the rear guide/anchor group and 135 g for
the front idler assembly; dynamics allow 65 g and 150 g respectively. Stop collars
are fixed to the outer tube; their allowances are 90 g each. These are density
estimates, not weighed parts. Do not silently omit this hardware from inertia.

## Remaining release gates

Select actual belt/pulley SKUs and verify tooth engagement, tension, clamp pullout,
fatigue and repeatable tension adjustment. Qualify collar grip and single-pin stops
on a restrained horizontal rig. Measure extension force/current throughout travel,
including tolerance extremes. Confirm supplier bearing fits and all screw grip
lengths. Complete guards and flexible wiring. Full-speed hard-stop tests require
containment and a measured energy/force limit; start with hand and low-energy tests.

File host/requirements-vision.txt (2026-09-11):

# Optional image detection dependencies tested together in the local QA venv.
# Core kinematics/planning/estimation/simulation tests use the standard library.
numpy==2.5.3
opencv-python==5.0.0.93

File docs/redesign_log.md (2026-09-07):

# Redesign Log

Template for each failure → fix cycle (spec §51).

| ID | Date | Problem | Measurement | Hypothesis | Change | New measurement | Result |
|----|---|---|---|---|---|---|---|
| R0 | — | Pitch torque vs budget | τ_req 16.3 Nm | NEMA23@8:1 borderline | Counterbalance 45% + SERVO57 | τ_req 11.9 Nm; capacity 17.6 | Resolved on paper |
| R1 | — | Yaw NEMA17 short | capacity 3 vs 7.2 Nm | Underpowered | NEMA23 @ 6:1 | 13.2 Nm capacity | Resolved on paper |

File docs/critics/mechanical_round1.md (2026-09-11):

# Independent mechanical / CAD / manufacturing critic — round 1

Review date: 2026-09-07. Scope: current Rev B telescope/claw source, exported studies,
engineering parameters/results/BOM, and original build/print guidance. This review
did not design or edit those main files. User requirement: genuine finger/claw
grabber with positive retention; no net. No live FreeCAD instance was touched.

## Verdict

Not ready to manufacture the complete robot or buy the three actuator systems.
The four explicitly unpowered fit parts can support dimensional experiments, subject
to the clamp/collision corrections below. The current CAD is an incomplete mechanism
study, and its own NOT RELEASED labels correctly acknowledge many omissions. A label
does not make those omissions disappear, but they are distinguished below from actual
calculation/geometry errors. Restrained hand-actuated tube and gripper experiments
are a useful next scope; high-speed powered extension, catch and throw are not approved.

Scores at this snapshot: mechanical design 4/10; CAD/manufacturing completeness 3/10;
3D-print design 5/10; cost efficiency against the requested complete $500 machine 3/10.
Scores describe the integrated design, not the usefulness of its investigation tools.

Severity S, likelihood L, performance impact P and cost of fixing later C use 1–5,
with 5 worst. Priority product is S×L×P×C. Likelihood here is likelihood of failure
if the present study were fabricated/operated as a completed design, not measured
failure frequency.

## Major findings

### M1 — actual collision in the fully retracted telescope (5,5,5,4; 500)

`build_review_telescope.py` puts the top catcher collar at x=538–560mm when s=0.
The front idler pitch-envelope center is x=545mm, and the belt lower run extends
to x=545mm. Independent FreeCAD 1.1.3 booleans give these positive intersections:

- BeltInsideEnvelope / CatcherClamp_top: 86.94mm³.
- IdlerPulleyPitchEnvelope / CatcherClamp_top: 179.24444mm³.

These occur for all four checked claw angles (-10, 0, 10, 20 degrees). Therefore
the nominal zero-stroke CAD cannot exist physically even before adding real idler
flanges and bearings. Current `verify` tests the clamp only against inner/outer
tubes, so its valid result misses the issue. Change the nose/clamp/idler layout,
then sweep every moving mount against the actual purchased drive envelopes. A
clearance cut is acceptable only if the remaining top clamp and load path are sized.
Do not merely hide the overlapping part or redefine zero travel after building.

### M2 — flat-guide friction uses the wrong normal-force combination (4,5,4,4; 320)

`guide_load` and `guide_bound` use hypot(pitch_reaction,yaw_reaction) for friction.
These square tubes have orthogonal flat shoe faces, not one bearing face normal to
the resultant. Separate face normals add: N=|Rp_front|+|Ry_front|+|Rp_rear|+
|Ry_rear|+preload. The current expression can understate the reaction contribution
by up to sqrt(2) in simultaneous pitch/yaw loading. Replace it and independently
check both single-plane and equal-plane cases. Account for the small drive-line
eccentricity if needed; at max stroke 2×0.15×0.0143/0.19≈0.023, so that alone does
not justify claiming this telescope self-locks, but it should not be ignored in a
final friction margin.

Pressure area is also inconsistent: JSON assumes one 30×9mm patch, whereas CAD
has two 30×5mm strips on each top/bottom face and one 30×18mm side pad. Use each
actual loaded face area and unequal load-sharing sensitivity. One narrow strip
may take essentially the full reaction under skew, doubling nominal face pressure.

### M3 — split collar bottoms out before establishing grip (4,5,4,3; 240)

`split_collar` has a bore 0.4mm larger than the tube and two mating surfaces both at
z=0. There is no designed split gap or compression liner. Tightening four M4 bolts
first mates the flange faces; positive grip would rely on unspecified bending of
the printed flange. Add controlled mating-face relief or a specified conformable
liner with a measurable remaining clamp gap and metal compression-limit strategy.
Prove axial pullout and rotational slip without crushing the 1.59mm tube wall.
Do not substitute high screw torque for an intentional clamp geometry.

### M4 — central extension mechanism and support load paths remain unclosed (5,5,5,5; 625)

Declared gate, not a falsely claimed release: the rear carriage/pad fasteners, belt
end clamp, tensioning adjustment, front pulley bearings/bracket, motor bracket,
mechanical end stops, root trunnion attachment and pitch/yaw frames/reductions are
not detailed. Current trunnions float outside the tube; current pads float in the
annulus. An open belt line with no anchorage is not a bidirectional extension drive.
The 4.76mm annular gap must contain the actual belt tooth/back thickness and clamp
through the full travel, not just a 1.38mm belt envelope.

Close the restrained extension-rig mechanism first: removable rear cartridge with
positive axial retention, belt clamp that is inspectable before insertion, adjustable
front wear carriers, purchased pulley data, both stop contact paths, and a numbered
assembly sequence. Add full assembly collision checks and fastener access envelopes.
Do not release the rotational assembly until the trunnion-to-tube torque path, hub
grip, brake and independent drop restraint have drawings and load checks.

### M5 — claw is not yet an actuated grabber (4,5,5,4; 400)

Declared gate: there are three real separate links and steel pin envelopes, but no
spring seats/reaction legs, physical open/closed stops, tendon routing/equalizer,
servo mounting or demonstrated release stroke. A servo envelope provides none of
these. A rigid equal tendon splitter may prevent one finger accommodating an off-center
ball unless slack/compliance is intentional. Route each tendon with a controlled
moment arm across travel; specify spring preload, force, overtravel, pinch points
and the power-loss retention/release behavior.

The current illustrative closure time is 104ms versus 15ms for a ball crossing
60mm at 4m/s. This is honestly disclosed and is a fundamental architecture constraint,
not something software timestamps alone fix. Test prepositioned claws and compliant
contact retention before pursuing faster actuation. A net is not proposed. The
4mm TPU palm cannot be credited with 25mm stopping stroke without force–displacement
testing and a model of its backing, support ears and replaceable foam.

### M6 — declared inertia/actuator/impact envelope does not support requested speed (5,4,5,5; 500)

The variable-inertia equations correctly include translated full-length tube mass and
I-dot coupling. The snapshot shows max-reach pitch demand 10.25Nm and yaw 7.94Nm
before impact; 1.5 torque margin requires 2.14/2.21Nm motor running torque at
160/120rpm. These exceed the candidate 2Nm holding labels, and extension requires
about 0.565Nm including margin at 1000rpm before the friction correction. The
model appropriately refuses approval. This remains a desk-design procurement gate:
obtain actual curves and select speed-dependent operating limits or a different
motor/ratio. It is not merely an unknown needing an entire robot prototype.

The unmatched 32N transverse catch adds 38.4Nm at 1.2m; the illustrative 12mm shaft
screen reports local-allowance yield factor ~0.47 for combined load. Do not approve
this event by calling foam safe. Bound the permitted relative velocity and approach
direction, qualify claw compliance, and size the complete transmission against the
accepted event. Physical impact tests should begin with an isolated restrained claw.

### M7 — distal mass allowance has no assembly budget (3,4,4,4; 192)

Independent CAD volumes: three claws 33.204cm³, palm 22.835cm³, palm pad 11.929cm³,
two collars 17.794cm³, two struts 5.478cm³: total 91.24cm³. Typical solid-density
conversion near 1.2–1.3g/cm³ gives about 113g before servo, steel pins, four M4
bolts/nuts, other screws, springs, tendons, foam and wiring. This is an envelope
screen, not a claim that a sparse print weighs its solid volume. The 130g allowance
is tight and must be supported by slicer plus purchased-hardware mass accounting.
The printed parts are mostly thin sections, so infill savings are smaller than
for thick blocks. Weigh the complete distal assembly and update COM and inertia.
Remove flange/annulus material by load-path-aware ribs if needed, not all-solid
infill or a heavier servo. Separate ball seating COM from nominal mouth plane.

### M8 — contradictory fabrication guidance is still active (4,4,4,4; 256)

Original `cad/drawings/print_guide.md` still describes the older CF round-tube build,
allows printed hinge pins, says the STLs form a real prototype fabrication cut-list,
and treats shields as optional; `requirements.md` still permits cradle/net wording.
This conflicts with current square tubes, steel pivots, no-net user requirement,
containment and NOT RELEASED states. Supersede the old cut-list prominently and
quarantine old outputs as legacy examples. A user must not accidentally order the
old tube sizes or believe the new review approved the old full-robot STLs.

### M9 — budget has no feasible complete-machine architecture (3,5,5,5; 375)

The new BOM correctly totals $1,077.30 before shipping/tax/reserve and $1,387.56
with disclosed allowances, nearly 2.8 times the $500 maximum. This is honest
accounting, not cost optimization completion. The basic extension-rig group alone
is $336.10 before safety, claw and allowances. The overrun cannot be closed by
printing shafts or deleting brake/containment. Determine owned parts and obtain
exact alternate motor/driver quotes; compare borrowed electronics and a manually
operated tube/claw phase. Keep each scope's costs explicit. No claim of a complete
safe high-speed $300–500 machine is defensible at this snapshot.

## Minor findings and improvements

- (S2,L4,P3,C2) Claw clevis gap is 12mm while the finger is 8mm thick, leaving 4mm
  axial space. Specify two 2mm thrust spacers or the intended alternative, actual
  M3 shoulder length, washer/nut stack and clearance; do not clamp rotating plastic
  tightly with the retaining nut. The 3.3mm printed pivot bore needs coupon/reaming
  validation against 3mm metal pin wear and backlash.
- (S2,L3,P3,C3) Two round 7mm printed catcher struts and annular palm leave mount
  compliance outside the tube-only deflection model. Check asymmetric contact and
  torsion, fillet strut-foot transitions, and give a reproducible lateral-load test.
- (S2,L4,P2,C2) Guide fit coupon has ideal square external corners. Real extrusion
  bore radii/straightness may reject it before face-clearance conclusions are useful.
  Relieve corners based on measured stock and document which coupon dimension tests
  face fit versus corner fit.
- (S2,L3,P2,C2) Nominal square-pad top/bottom preload needs adjustment and lock
  features. Overconstrained tightening is a credible jam source even when all
  nominal CAD shapes do not intersect; record pull force at many strokes and orientations.
- (S2,L4,P3,C3) Use a retained removable cover over the external return belt and
  avoid routing distal wiring through the same top corridor without a bend-radius
  and full-stroke harness trial. The harness belongs in the moving mass budget.
- (S2,L3,P2,C2) `verify` should assert one solid per manufactured component, not
  merely nonempty `Solids`. Independent spot checks currently found one solid in
  every one of the 33 objects, but the invariant should survive future edits.

## Independent checks and limitations

FreeCADCmd 1.1.3 built source at four claw angles, checked one solid per object,
and computed boolean intersections for claws/palm/pad/servo and drive versus
catcher mounts. No tested claw–palm/pad/servo collision was found. This does not
cover undefined springs/tendons/hardware or the complete yaw/pitch workspace.
Tube overlap independently follows 520-(−220+s)=740−s mm at the relevant interval,
giving 240mm at max stroke; guide spacing 490−(−200+s)=690−s mm gives 190mm.
These are credible improvements over unsupported guide placement, but retention
is still needed. No finite-element or supplier-material certification is claimed.

## Revision priorities and prototype boundary

1. Correct full-retraction belt/idler collision, collar clamping gap, square-guide
   friction/pressure model and contradictory fabrication status.
2. Finish an inspectable extension drive, pad cartridge and hard-stop load path.
3. Complete the claw spring/tendon/stop/servo mechanism and hardware stack.
4. Select motors only from torque-speed/current/thermal data at actual bus voltage;
   reconcile moving masses and price a buildable scope.
5. Perform unpowered dimensional/pull-force tests, restrained claw drop/retention
   tests, then restrained low-energy powered extension after hardware safety review.

Desk-solvable items are mechanism closure, drawings, dimensions, conflicts, motor
data, cost and mathematical errors. Physical unknowns are actual guide friction,
wear, extrusion straightness, print strength/creep, assembly stiffness, mass,
claw stopping stroke/rebound, motor heating and harness life. The current major
unknowns are not predominantly physical-test unknowns; several major design
decisions still require desk work before buying the complete machine.

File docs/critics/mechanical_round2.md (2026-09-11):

# Independent mechanical/CAD critic — round 2

Review: 2026-09-07. Snapshot: `build_review_robot.py` producing 219 solid objects at
250mm extension, yaw 0°, pitch 20°; current `telescope_guides.py` and telescope/claw
source. The original GUI assembly was not accessed or modified. This audit used
FreeCADCmd 1.1.3 and broad-phase bounding boxes followed by solid intersection
booleans. It did not change implementation files. Several parts are deliberately
supplier envelopes or NOT RELEASED studies; those statuses are preserved here.

## Verdict and scores

The full model now represents the robot's architecture, but it cannot yet be
assembled as drawn. The first telescope collision and clamping issues were addressed;
the new full assembly introduces major preventable intersections and disconnected
bearing interfaces. These are desk-design issues, not uncertainty requiring powered
prototype testing. Do not call the full model manufacturable or infer approval from
its 219 valid objects.

Scores for this snapshot: mechanics 4/10; full CAD/manufacturing readiness 3/10;
3D-print design 5/10; cost efficiency against the requested complete-machine budget
3/10. Approval scope remains isolated unpowered fit/guide/claw experiments. The
new ESP32/servo ownership information improves the phased rig budget but does not
close the complete-machine budget or hardware qualification.

S/L/P/C below mean severity, likelihood, performance impact, and cost of fixing later,
each 1–5. These are ordinal design-review priorities, not probabilistic estimates.

## Resolved or improved since round 1

- The inner tube is 805mm and reaches x=585mm when retracted, moving its collar
  away from the front belt/idler. The intended 700mm mouth reference remains.
- The collar has 0.4mm relief per split face and shorter external ears; the previous
  flange bottoming defect is addressed geometrically. Clamp friction/crush proof remains.
- Claw hinges now include two 2mm spacers around each 8mm link in its 12mm clevis.
- Acetal front/rear shoes now have recessed M2 retention screws, washers, nuts,
  staggered opposing service holes, and documented assembly access. This is a real
  improvement over floating pads. Actual preload, wear, straightness and fastener
  durability remain physical test gates.
- Major support frames, bearing spacings, reductions, motors, brake and guarding
  are now represented in a full assembly. The model no longer relies on a solid
  shaft passing through the telescoping tube. New geometry errors follow below.

## Major concrete findings

### R2-M1 — yaw output pulley passes through all four cage posts (5/5/5/4)

The 80T HTD5 pulley pitch radius is 63.662mm. Cage posts are centered at x/y=±40mm,
radius 56.569mm, each with 6mm outside radius. Each post intersects `YawOutput80`
by 709.969mm³. This is a structural collision, not a cosmetic overbound belt-ring
artifact. The 80T output is also different from the old 60T output documentation.

Move the posts outside the actual pulley flange and belt swept envelope, or change
the reduction geometry. A starting post center at ±55mm gives radial distance
77.78mm, but requires corresponding wider upper deck, hole pattern and guards;
actual flange OD, belt width and clearances must still be checked. Re-evaluate
torsional stiffness and cost after the change. Do not notch away a load-bearing post.

### R2-M2 — pitch jack pulley occupies a bearing (4/5/5/4)

`PitchJack20` is centered at y=110mm with width 9mm, so its envelope spans
105.5–114.5mm. `PitchJackBearing_102` spans y=102–110mm. Their solid overlap is
2,261.947mm³. A pulley hub would need more space still. The inner bearing, pulley
planes and support plate must be laid out as one axial stack with positive shaft
retention. Add a direct pulley/bearing nonintersection assertion.

The other pitch jack bearing spans 146–154mm, while its support plate starts at
154mm. The bearing ends at the plate face rather than seating inside a housing.
The yaw upper jack bearing similarly ends at z=476mm where its plate begins.
These interfaces have no meaningful radial support across the bearing width;
matching hole diameters in the adjacent plate do not support a floating bearing.
Use a full-width removable cartridge or an intentional shoulder/retainer housing.

### R2-M3 — brace layout installs multiple solids and bolts in the same space (4/5/4/4)

Opposite diagonal braces share the same upper endpoint and plate plane. Each
opposed pair intersects by 1,933.764mm³. The source emits two identical upper
bolts for each opposed pair, causing 1,958.591mm³ duplicate hardware. The two
orthogonal bolt directions also cross at z=300mm, producing 144mm³ intersections.
Only one crush sleeve direction was modeled at that height; it cannot support
all the specified orthogonal tightening loads.

Stagger the two orthogonal brace heights and deliberately stack the two same-plane
links using one shared bolt and appropriate spacers, or place them on opposite
column faces. Add a crush sleeve matching each installed cross-column bolt. The
brace lower ends currently penetrate the base plate by 69.255mm³ each and their
foot brackets by 129.279mm³ each; raising/repositioning the lower pivot and ensuring
adequate edge distance is necessary. Check the full flat-link circular end, not
only the hole center. Avoid treating intersecting links as a welded assembly.

### R2-M4 — yaw shaft and motor/jackshaft cross unrelated solid structure (4/5/5/4)

- `YawKeyedShaft20` intersects `ColumnCrushSleeve_390`: 422.623mm³.
- `YawJackshaft12` crosses the unbored `YawLowerDeck`: 678.584mm³.
- The yaw motor shaft intersects `YawLowerDeck`: 190.015mm³.

Set the main shaft lower end clear of the mast sleeve or relocate the sleeve while
preserving the column-cap fastening path. Provide the real jackshaft bearing bore
and housing at its location. Mount the selected yaw motor against a deliberately
bored mounting face with register, shaft and bolt clearance; do not simply drill a
small shaft hole if the motor needs a register and 8mm offset to the existing deck.

### R2-M5 — support and fastener patterns disagree (4/5/4/4)

The yaw cage spacer centers are ±40mm, but the corresponding deck/cartridge hole
pattern is ±29mm. The posts also intersect the lower cartridges by 153.247mm³ each
and their caps by 25.541mm³ each. Define separate cartridge bolts and cage tie rods,
with real matching holes and unobstructed nuts. The yaw jack upper support holes
are x=−140/−90, y=±25mm, while its four spacer centers are x=−145/−85, y=±27mm;
these cannot take the claimed through tie bolts.

`YawHubPlateSpacer` has no four M6 holes, so each modeled hub screw crosses its
solid by 84.823mm³. Bore the common four-hole pattern through the complete stack.
`YawUpperShaftCollar` spans z=519–527mm while the flange starts at 525mm, producing
1,183.442mm³ overlap. Set an intentional bearing-inner-race shim/collar/hub stack;
moving a collar must not leave the bearing axially unsupported.

### R2-M6 — drive backplate and guards cut into structural/actuator parts (4/5/4/3)

- PitchDriveBackplate / RotatingTurretPlate: 1,098mm³.
- PitchDriveBackplate / YokeFootAngle_2: 963mm³.
- PitchBeltGuardEnvelope / PitchMotorCandidate: 6,498mm³.
- Each yaw cage post crosses the yaw guard: 157.771mm³.

The backplate currently begins below the turret and lies in the foot-angle volume.
Move its interface or provide actual matching relief and a bolted support angle;
do not pretend overlap provides attachment. Guards may be packaging envelopes, but
their present sheets cannot be cut and installed. Provide deliberate motor/body
openings or move the enclosure boundary and retain coverage of belts and pinch
points. Recheck access to motor plugs and brake fasteners after the change.

### R2-M7 — full verification covers too few interfaces (4/5/4/5)

The existing full `verify()` asserts four stub/rail shapes do not intersect the two
tubes. All eight checks pass while the collisions above remain. Shape validity and
ratio multiplication also pass. Add a categorized collision report across parts,
with explicit exclusions only for intentionally overlapping belt pitch-ring/pulley
envelopes and wire exclusion zones. Do not blanket-ignore all purchased envelopes:
a bearing inside a pulley or a motor through a guard is still an actionable issue.

Maintain explicit expected-contact pairs and nonintersection pairs for mechanical
parts and check at least endpoint/intermediate angular poses. A passed neutral
pose cannot establish the full yaw/pitch motion envelope. Bolt-hole alignment,
bearing-seat engagement and tool access need additional checks beyond booleans.

## Other observations

- (S2/L4/P3/C3) Two small catcher strut/top-clamp overlaps remain, 21.868mm³ per
  strut, after the shortened root mounting. They are now much smaller than the old
  idler clash, but distinct printed parts must not occupy the same volume. Inspect
  the round strut beginning near its foot and relieve/reposition the contact geometry.
- (S3/L4/P3/C3) Yaw belt pitch envelopes intersect two drive spacers (47.567mm³
  for stage 2; one stage-1 interference 104.415mm³). The intentionally complete
  pulley rings may overstate some arcs; test against the actual exposed tangent
  spans and actual wrap before deciding which posts to move. This is not included
  among unequivocal solid structural clashes above.
- (S2/L3/P3/C3) The shoe strip width is now 6mm on top/bottom rather than the old
  5mm. The recessed 4.2mm counterbore leaves only 0.9mm side ligaments locally.
  Verify acetal fastener preload and strip fracture under pullout and single-pad
  edge loading. Do not torque M2 screws as though these are metal bracket ears.
- (S2/L3/P3/C2) Two screws per strip and opposing access holes are useful, but the
  30mm guide section is heavily perforated. The tube-only bending model does not
  resolve local hole net-section fatigue. Document deburring and inspect guide
  hole edges after initial load cycles.
- (S3/L4/P4/C4) Belt clamp, end stops, actuator anchorage and claw tendon/spring
  reaction details still require closure. Those were already explicit design gates;
  they are not counted again as newly discovered bugs. Root owns the in-progress
  servo mount work, so this snapshot does not rate that unfinished update.

## Independent mass and geometry checks

The fresh headless build reproduces 219 solid-bearing objects and pitch/yaw ratios
8:1 and 6:1. Four timing-belt compounds each contain four solids, deliberately;
all other modeled objects in this snapshot have one solid. Root tube/stub separation
is valid. The following numbers are geometry/allowance screens, not weighed masses:

- Added stationary parts: 6.0313kg.
- Added yaw-only parts: 4.3109kg.
- Added pitch parts: 1.1238kg, including extension drive envelopes/plate.
- Added yaw-only inertia about yaw: 0.094646kg·m².

The engineering yaw allowance 4.5kg at radius 0.16m gives 0.1152kg·m², above this
0.094646 screen by about 22%. This is a reasonable provisional allowance for the
modeled yaw group, not certification: unmodeled bolts/hubs/guards and revised
collision-free geometry can consume it. Imported telescope, shoes, hardware and
claw are explicitly excluded from these CAD totals and must not be omitted from
the separate boom dynamics. Do not present 4.31kg as the complete yaw-carried mass.
The model's overlapping/doubled braces also slightly inflate stationary mass until
corrected; removal is a geometry fix rather than a meaningful speed optimization.

## Required next design pass

1. Close the yaw cage/output-pulley envelope and pitch jackshaft bearing/pulley stack.
2. Correct brace stacks, through-bolt heights, column sleeve/shaft conflict and all
   matching mounting-hole patterns.
3. Seat every bearing across its required radial support width and define the axial
   race/shaft retention paths.
4. Resolve backplate/turret/guard/strut intersections, then run full categorized
   collision checks over meaningful poses.
5. Recompute moving mass/inertia and BOM before sourcing motors or framing this as
   full CAD ready for manufacturing. Continue isolated low-cost subsystem trials.

No physical test is needed to decide whether two solid parts may occupy the same
space. Fix these desk issues first. Physical tests then determine guide friction,
creep, compliance, retention, backlash, heat and durability of an assembled mechanism.

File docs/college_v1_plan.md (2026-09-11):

# College V1 and fair-version budget — 8 September 2026

**Superseded V1 cost/classification:** use `college_v1_named_bom.md` and the current
`engineering/bom_college_v1.csv`. The new named print-first basket is $368.47 parts,
$446.55 with assumed shipping/tax, or $513.53 including optional repair reserve.
The $705.64 V1 allowance and metal-only cap/pulley guidance below are historical.

## Answer

A compact, slow, mostly printed robot with powered yaw, pitch, telescope and a real
three-finger claw has a current planning basket of **$547.86 in parts; $705.64
including $65.74 shipping/tax allowance and $92.04 redesign reserve**. Treat roughly
$650–800 as an initial planning range, not a quote or guaranteed ceiling. Exact
CAD, actuator selection and supplier prices can move it outside that range.
This is a new compact concept, not the current full-size CAD converted to plastic.

The current higher-performance full-machine/fair-direction basket is **$1,131.30
parts; $1,457.12 with allowances**. It includes $100 for stereo cameras/accessories,
but its actuator and voltage choices still need revision. It is not an approved
shopping list or a final guaranteed cost to achieve high-speed catching.

The restrained horizontal telescope/claw rig remains **$497.29 with allowances**.
It demonstrates extension, sensing and claw tests, but has no powered yaw/pitch.
These are three alternative initial baskets, not three costs to add together.

## What V1 would demonstrate

Proposed compact geometry: approximately 350–550 mm reach, 200 mm telescope stroke
and a 350 mm shoulder height. Initial design targets are slow motion, a lightweight
foam ball no more than 20 g, coordinated movement, homing, repeatable extension,
and commanded gripping/release. These are proposed limits to qualify, not approved
powered operating settings. No camera is included: vision tracking, autonomous
interception and throwing are later capabilities, not claims for this V1 budget.
Adding the present stereo allowance adds $100 parts, approximately $129 with the
same allowances. A single camera could support a constrained-plane experiment;
it does not replace general 3D stereo without a different measurement method.

## Print versus buy

Print the compact shoulder/yoke as a ribbed box structure, motor brackets, bearing
carriers, large pulley webs with metal hubs, palm, rigid fingers, guards, cable
supports and fit fixtures. Use through-bolts and metal compression sleeves where
preload would creep through plastic. Printed bearing seats need retention and
replaceable fit inserts. These are redesign tasks, not permission to print the
existing 3 mm aluminum cheek geometry unchanged.

Printed inner/outer boom shells are reasonable to investigate for the SHORT V1.
Use longitudinal load paths, real low-friction wear strips, replaceable joints
and mechanical retention. A short tube that fits the printer as one part is much
better than several thin butt-jointed sections. Printer bed size is still unknown.
Keep aluminum tubes as the preferred fallback if straightness, binding or joints
consume more time and filament than the tube stock saves.

Keep steel shafts, screws, nuts, pins, bearings, springs, bearing caps, belt clamp
caps and small drive pulleys. Keep a rigid anchored base; plywood is acceptable
for a low-energy compact prototype. Use bought foam/rubber pads instead of buying
a whole TPU spool solely for a few pads. This V1 budget buys two PETG spools and
allows rework; it does not assume free filament. Nylon and carbon-filled filament
are not default upgrades. Printed failure modes include creep, layer separation,
hole ovalization, belt hub slip and guide roughness.

## Why printing alone is not a $1,000 saving

The full-size aluminum tube pair is only $48.10 of the current parts basket.
Two printed 3 mm-wall shells of the same outside sizes have an ideal bending
stiffness about 18–19 times lower using a favorable 2.31 GPa PETG XY coupon modulus.
That comparison excludes joints, creep, layer-direction effects and guide play.
They weigh only about 13–14% less per metre in this ideal solid-wall calculation.
A shorter span improves deflection strongly, which is why a compact V1 deserves
its own architecture rather than the original long arm in plastic.

Reproduce with `python -m engineering.v1_print_trade`. PETG source:
https://polymaker.com/wp-content/uploads/lana-downloads/TDS_Polymaker_PETG_V2.0_2025-11-17.pdf
Coupon values are not a printed structural design allowable.

The major V1 savings come from reduced reach, smaller motors/drives, simpler
support structure and postponed high-speed perception. Purchased low-cost NEMA17
motors are a price reference only; $9.62 each was observed on 8 September 2026:
https://www.omc-stepperonline.com/nema-17-bipolar-59ncm-84oz-in-2a-42x48mm-4-wires-w-1m-cable-connector-17hs19-2004s1
Their 0.59 Nm holding rating is not running torque. The driver allowance is $20 per
axis; the cheaper DM320T has only about 1.56 A RMS and cannot be credited with full
2 A motor torque. Output feedback, independent power interruption, regeneration
protection and pitch power-loss restraint remain budgeted.

## Avoid spending twice

ESP32/host tooling, calibration procedures, claw test results, measurement scripts,
fasteners and some power/interface hardware may transfer to the fair version.
Do not assume compact motors, printed booms, brake, belts or a 120 W supply will
transfer to the larger robot. The future fair budget is a full basket; actual
incremental upgrade cost requires subtracting only compatible reused components.
Borrowing school printer access, camera equipment or suitable hardware can lower
cash cost, but no unconfirmed loans are counted. Printer purchase, bench, ordinary
tools and host computer are excluded. Unknown owned servo is not credited yet.

## Work completed on the full design in this pass

Both repository GIFs were regenerated from the complete 381-part CAD. The model
now includes raised/windowed shoulder supports, rear telescope belt anchor and
stop hardware, a connected extension motor bracket, supported front idler and
claw spring/stop/tendon allowances. Five sampled full-robot poses had no unresolved
solid intersections above 0.5 mm3, and animation placements agreed with a separately
built pose for all 381 parts. This is sampled evidence, not continuous collision
validation. All 62 host/engineering tests pass after mass updates.

At 0.70/0.95/1.20 m reach the updated pitch inertia is approximately
0.2555/0.3877/0.5967 kg m2; target-motion pitch torque bounds are
5.66/9.04/13.05 Nm. Current motor/reduction choices do not qualify those targets.
The smooth 5 mm stop-pin screen was updated to match the actual CAD and assumes
single-pin first contact; pad stroke and impact pulse still require measurement.

## What still requires design, and what requires hardware

Desk work: compact V1 CAD and sizing; final fair drive ratio/voltage selection;
complete claw equalizer/servo horn; complete cable/guard/brake envelopes and swept
collision checks; supplier-specific fits and assembly drawings; ESP32 port.
The actual servo and ESP32 model are still needed for their final interfaces.

Prototype work: printed joint/guide fit, tube straightness, collar and belt-clamp
slip, stopping stroke/force, spring preload, servo current/closure time, motor
running torque/temperature and repeatability. None can be established from a GIF.

Next priorities are: choose the compact dimensional baseline; complete its
motor/reduction and pitch-restraint sizing; build its print-oriented CAD; qualify
telescope and claw on a restrained rig; then integrate yaw/pitch and measured
motion before adding autonomous ball interception.

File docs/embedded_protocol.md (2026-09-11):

# Embedded protocol v2 and implementation boundary

This document supersedes the v1 protocol section in the original architecture
document. Both endpoints must be updated together. V1 has no compatibility fallback:
its signed 16-bit millidegrees cannot represent the required ±70 degree travel.

## Wire format

Little-endian, signed two's-complement 32-bit motion/current fields, packed without
padding. Supported targets are Teensy 4.1 and little-endian native test hosts.
`protocol.h` compile-time size assertions and the Python/C++ cross-language test
check the exact layout. USB CDC is configured at 921600; the host is not a hard
real-time scheduler.

Command is **44 bytes**, Python struct `<HBBIIBB6iB3sH`:

- Bytes 0–1: magic 0x5AA5 (wire A5 5A).
- Byte 2: version 2; byte 3: total size 44.
- Bytes 4–7: unsigned sequence; bytes 8–11: host monotonic timestamp microseconds.
- Byte 12: command ID; byte 13: flags, must be zero.
- Bytes 14–37: six signed int32 values: yaw mdeg, pitch mdeg, extension stroke mm,
  yaw mdeg/s, pitch mdeg/s, extension mm/s.
- Byte 38: legacy latch field, must be zero; bytes 39–41: reserved, must be zero.
- Bytes 42–43: CRC16/MODBUS of bytes 0–41, initial 0xFFFF, reflected polynomial
  0xA001, no final XOR. Check vector ASCII 123456789 gives 0x4B37.

Telemetry is **62 bytes**, Python struct `<HBBIBB12iHH`:

- Bytes 0–3: identical header except total size 62.
- Bytes 4–7: MCU microseconds since boot (wraps approximately every 71.6 minutes).
- Byte 8: state (Boot=0, SelfTest=1, Disabled=2, Idle=3, Active=4, Fault=5).
- Byte 9: capture sensor 0/1, or 255 when unavailable.
- Bytes 10–57: signed int32 triples of measured position, measured velocity,
  commanded target, measured current mA; angular units remain mdeg.
- Bytes 58–59: fault bits; bytes 60–61: CRC over bytes 0–59.
- INT32_MIN is **missing**, never zero. Python converts it to None. Targets are
  setpoints only and are never evidence of measured motion.

## Commands and freshness

NOP=0, ENABLE=1, DISABLE=2, SETPOINT=3, HOME=4, TRAJ=5, CLEAR_FAULT=6,
RESET_LINK=7. Non-setpoint commands require all motion fields zero.
HOME and TRAJ return an unqualified fault; no motion adapter exists. Nonzero claw
actuation is rejected rather than controlling a servo without feedback.

ENABLE always leaves the qualification fault asserted. DISABLE is accepted with
any sequence after CRC/semantic validation and preserves real faults. RESET_LINK
resets the receive sequence baseline only when motion is disarmed; it cannot clear
faults or arm. The host connection sends DISABLE followed by RESET_LINK.

Normal sequence acceptance is `0 < (new-old) mod 2^32 < 2^31`; duplicates, backward
and half-range-ambiguous packets do not refresh freshness. CRC/header/semantic
validation precedes freshness refresh. No outgoing command retry or background
heartbeat silently keeps an old trajectory running.

Current timeouts: inter-byte 20 ms, loop-overrun diagnostic 2 ms, host traffic 200 ms,
setpoint stream 50 ms. The parser reads at most 128 serial bytes per scheduled cycle,
uses a fixed 44-byte buffer, and resynchronizes after corruption, insertions and
dropped bytes. Telemetry is best-effort at 100 Hz and skips transmission if the USB
buffer lacks space. The host bounds a poll to 4096 bytes and rejects stale, faulty,
inactive or missing-feedback telemetry before a setpoint write.

The host timestamp is diagnostic only: clocks have no synchronization contract.
MCU arrivals use local time. A CRC is error detection, not authentication. RESET_LINK
does not establish cryptographic replay protection or a new boot identity. Before
an enabled production protocol exists, add a board-generated boot/session challenge,
command acknowledgement and scheduled-execution/deadline semantics; queued USB
traffic and stale sequences must then be tested across every reset/reconnect case.

## Implemented versus absent

Implemented: version/range/CRC/framing validation; rollover-safe sequence comparison;
bounded parsing; valid-arrival freshness bookkeeping; missing-measurement decoding;
persistent qualification lock; NC switch diagnostics; no automatic arm or retry;
zero untuned controller gains; finite checks, reset and conditional anti-windup.

Absent: step/dir or vendor serial motor adapters, real joint feedback and age checking,
current measurement/thresholds, homing, hardware watchdog setup, qualified gain
scheduling/feedforward, acceleration/jerk execution, stopping envelope, brake timing,
joint output position supervision, capture feedback and three-finger claw actuation.
The target scheduler is a cooperative 1 kHz diagnostic loop, not measured deterministic
closed-loop control. Do not connect a loaded robot on the strength of software tests.

Firmware commissioning cap is 20 degrees/s yaw/pitch, 150 mm/s extension. The
host packer matches it; higher simulation requirements cannot be sent to hardware.
Extension is **stroke**, not total reach: L = 0.700 + extension_mm/1000 meters.

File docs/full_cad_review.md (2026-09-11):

# Full Rev B CAD — revised assembly status

The current connected full-robot prototype uses an 850 mm shoulder, windowed
3 mm cheeks and stock-angle stiffeners. It preserves yaw +/-70 degrees and pitch
-15 to +70 degrees. Raising the shoulder corrects the earlier 650 mm geometry's
sampled high-pitch collision. Five final poses at retracted, intermediate and full
extension have 381 valid modeled parts and no unresolved part intersections above
the collision screen threshold. These samples are not continuous swept clearance.

The raised yaw structure adds about 0.866 kg relative to the old baseline after
windowing; total added yaw CAD group mass is 5.221 kg. Telescope rear anchor,
stop collars/pins/pads, motor bracket and supported front idler are now modeled.
Claw springs, stops and short working tendon segments are modeled; actual servo
termination/equalizer and complete cable routing remain unfinished. See the new
`telescope_drive_design.md` and `claw_actuation_design.md` for precise limitations.
The older findings below record design history; unresolved 650 mm collisions refer
to that superseded geometry. This model remains NOT manufacturing released.

## Problems corrected after independent round 2

- **Yaw pulley/cage collision → blocked rotation → moved cage posts to x=±40,
  y=±65mm with matching deck holes and a 130×150mm upper deck → slightly larger
  stationary deck.** Posts now clear both the 80T pitch disk and stage-2 tangent;
  merely moving posts to x/y=±52mm cleared the disk but still hit the tangent.
- **Floating/intersecting jack bearings → unsupported shafts and impossible stack
  → full 8mm radial carriers, 3mm removable caps and common M4 patterns.** Pitch
  bearing starts are y=91 and 146mm; their pulleys remain centered at y=110/132mm.
  Yaw bearing starts are z=390 and 468mm. Opposite stock plates use 22mm shoulder
  apertures. Supplier fits, shims, inner-race collars and rated hubs remain gates.
- **Duplicate brace links/bolts and orthogonal bolt crossings → impossible assembly
  → stacked link planes 28/31mm, one shared screw per pair, upper heights 250/360mm,
  matching crush sleeves and 24mm lower pivots.** The unequal brace heights avoid
  broad-link crossings, including the intermediate positive-X/positive-Y members.
- **Yaw shaft/deck/sleeve collisions → blocked rotation → removed the 390mm cross
  sleeve, provided actual deck apertures, and mounted the yaw motor face at z=398mm
  against the deck underside with register and mounting bores.** Main-shaft shoulder
  and column-to-deck fastening details still require an exact hardware drawing.
- **Collar/hub overlap and unbored hub spacer → impossible stack → 4mm inner-race
  spacer at z=513–517mm, collar at 517–525mm, and common M6 holes through the hub
  spacer and turret.** Actual inner/outer-race axial shims remain unqualified.
- **Backplate/turret and motor/guard intersections → cut-in geometry → relieved the
  backplate below the turret/foot interface and moved the outer guard plane to
  y=250mm.** Complete guard sidewalls, brackets and brake/motor access remain open.
- **M4 saddle bolt too close to L-shoe upright → trapped nut/washer → widened the
  shoe foot and moved the rail/flange/stub interface outward by 5mm.** Bolt axis to
  upright distance is now 7mm, admitting nominal M4 hardware and a small socket;
  validate the actual socket and washer series. Matching turret/yoke foot holes
  were also added. Bolted clamp slip and thin tube crushing still require proof.
- **Narrow verification missed most failures → false confidence → added a broad
  bounding-box/boolean collision report.** Only exact own-belt/own-pulley pitch
  representation pairs are ignored. Cable routing-envelope contacts are reported
  separately; other purchased envelopes are not blanket-exempted.

Ratios remain pitch 20:40 × 20:80 = 8:1 and yaw 20:30 × 20:80 = 6:1. Supplier belt
lengths must match the intended centers with real tension adjustment. A pitch-path
ring is not a printable pulley or proof of supplier tooth engagement.

## What the independent headless checks show

The revised neutral assembly at extension 250mm, yaw 0°, pitch 20° produced zero
unresolved solid collisions after the parallel claw-mount corrections. At the
pre-final rail-access revision, added mass screens were stationary 6.5557kg,
yaw-only 4.3563kg, pitch-added 1.1238kg; yaw-only inertia was 0.099994kg·m². The
latest `_checks.json` and mass CSV generated from source supersede these snapshot
figures. Telescope, shoes and claw are separately imported and excluded from these
added-part totals; 4.3563kg is not the complete mass carried by yaw.

Sampled poses at pitch −15°, yaw ±70°, extension 0/500mm were clear. At extension
0mm, pitch 35° and 40° with yaw −70°, 0°, +70° were clear in modeled solids. At
45° pitch all three yaw samples collided with the rotating turret (about
296.6mm³); yaw 0° also collided with the upper jack support (~869.4mm³) and guard.
Thus onset is between the sampled 40° and 45° cases, not at 70° alone. This is not
a continuous collision-free range certificate or a new software operating limit.

At pitch 70°, the rear outer tube, retracted inner tube, extension pulley and
extension motor enter the yaw stack. At yaw 0°, extension motor/lower deck overlap
was about 11,291mm³; at yaw 70°, extension motor/yaw motor overlap was about
31,238mm³. Outer tube/hub and outer tube/turret interference persist with yaw, so
moving one guard or motor cannot solve the whole sweep. Extended stroke removes
some retracted-inner contacts but does not remove the fixed rear boom/motor conflict.

## Remaining desk-design decision: clearance over the required pitch range

The rear extension motor is about 275mm behind pitch. At 70°, its axial center
alone descends 275 sin(70°) ≈258mm; the rear 250mm outer tube descends ≈235mm.
Cross-section/motor-body depth adds further clearance demand. Retaining the current
650mm shoulder above the yaw stack therefore needs an architectural change.

1. **Lower the entire yaw stack and use a taller shoulder yoke.** Approximately
   150–170mm more vertical separation is a useful first packaging study, not a
   solved clearance value. Shortening the 50×50×2mm column by 150mm saves about
   0.156kg, while simply extending both 160×3mm yoke cheeks by 150mm adds about
   0.389kg before cutouts/gussets. Plain taller plates are not adequate by default:
   a cantilever height increasing from roughly106 to256mm raises a comparable
   bending compliance by about(256/106)^3 ≈14.1. Use triangulated/boxed stock load
   paths and repeat bearing alignment, stiffness and full sweep checks.
2. **Raise the shoulder with the yaw stack fixed.** Similar 150–170mm relative
   separation would put the pivot near800–820mm. It preserves boom inertia about
   pitch but adds yoke mass and height, changes the world pivot height, and raises
   base overturning moment. Tall thin printed cheeks are not an acceptable shortcut.
3. **Move pitch forward of yaw.** A small shift that clears the 70° endpoint can
   still collide at intermediate pitch. Study the whole sweep; offsets of order
   0.3–0.4m may be needed around this broad stack. Such an offset substantially
   increases yaw inertia: for pitch-moving mass M, first moment S and shift d,
   ΔI_yaw ≈M d²+2dS at horizontal pitch. At d=0.35m the M d² term alone is about
   0.29kg·m² for M≈2.4kg, before the positive first-moment term. This conflicts with
   low inertia, enlarges footprint and requires new noncoincident-axis kinematics.
4. **Shorten the rear telescope.** The rear overhang comes from the combination
   of 500mm stroke, 240mm minimum overlap and 700mm mouth reach. Cutting its tail
   loses either overlap, stroke or retracted reach unless the guide architecture
   changes. More stages add distal guides, compliance and routing complexity.
   Recalculate all lengths and inertia before treating this as a cheap cut-and-drill fix.

These are quantified options, not approved replacement designs. Keep the complete
hardware qualification lock in place. Do not quietly cap pitch to40° and call the
original 70° objective complete. A restricted unpowered fit fixture is a separate
test scope and must be described as such.
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

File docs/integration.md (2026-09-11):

# Integration and release checklist — Rev B

**Not released for powered autonomous operation.** Full CAD, simulation and a
compiled Teensy target do not close these interfaces. Follow docs/bringup.md for
work possible now and docs/safety.md for physical stop requirements.

## Mechanical

- Anchored base, braced stock support, separated yaw bearings and coaxial opposed
  pitch bearings. External trunnions need positive torque retention; no shaft
  crosses the sliding tube bore.
- Measured square aluminum stock, retained fixed/moving wear pads, adjustable
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

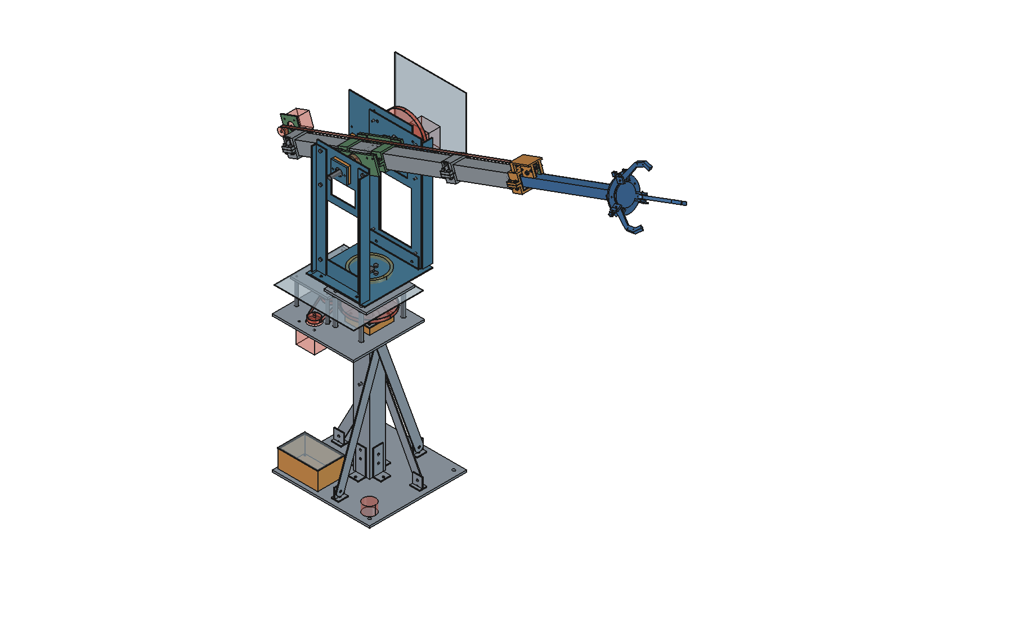
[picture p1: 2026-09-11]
VariableReachArm_Full_RevB.png

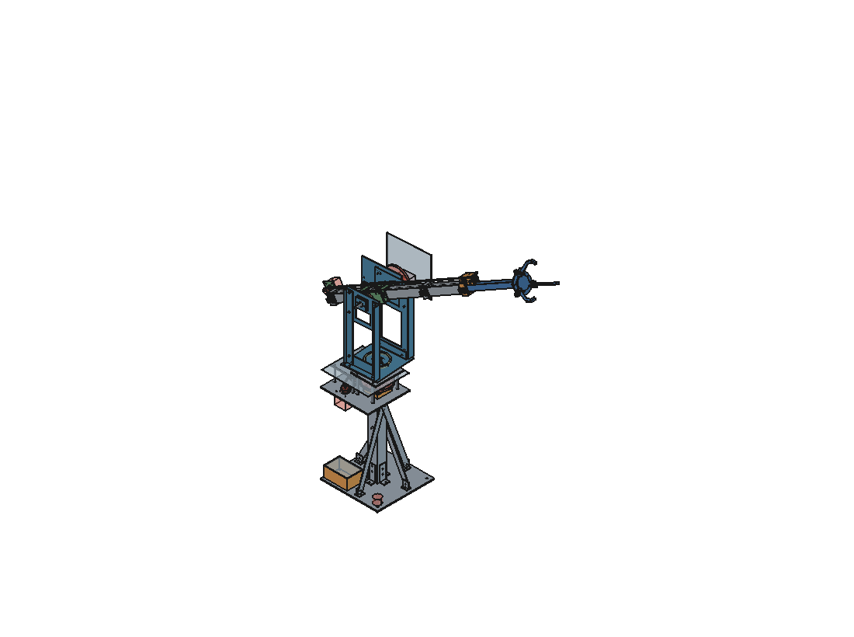
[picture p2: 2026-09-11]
cad/animations/frames_catch_fast/frame_029.png

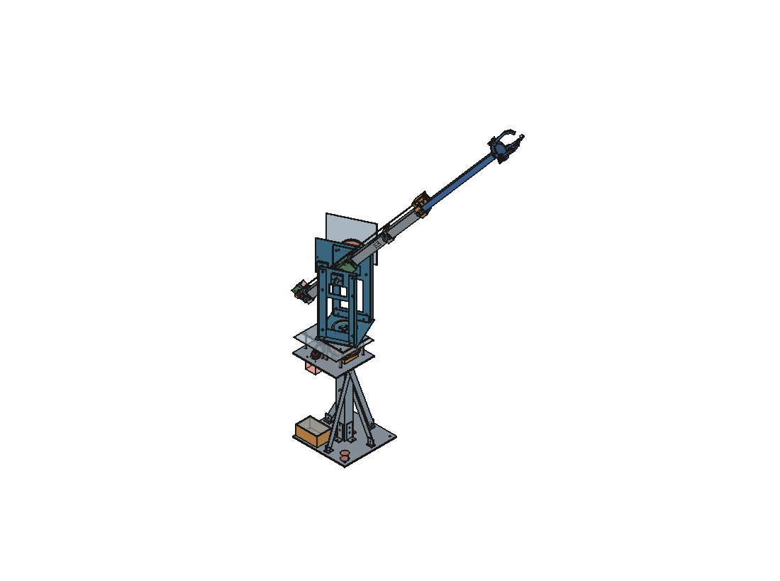
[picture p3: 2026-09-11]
cad/animations/frames_catch_fast/frame_056.png

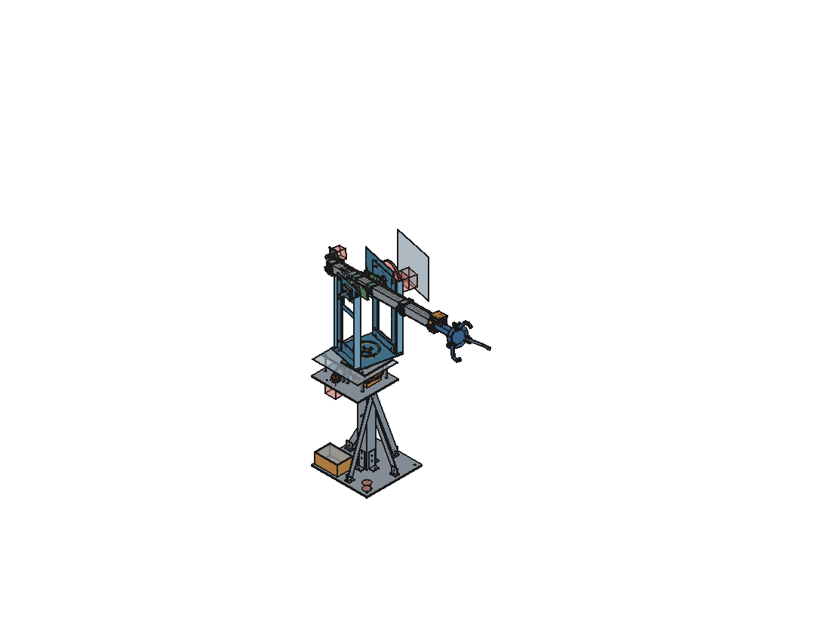
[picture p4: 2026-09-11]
cad/animations/frames_catch_fast/frame_023.png

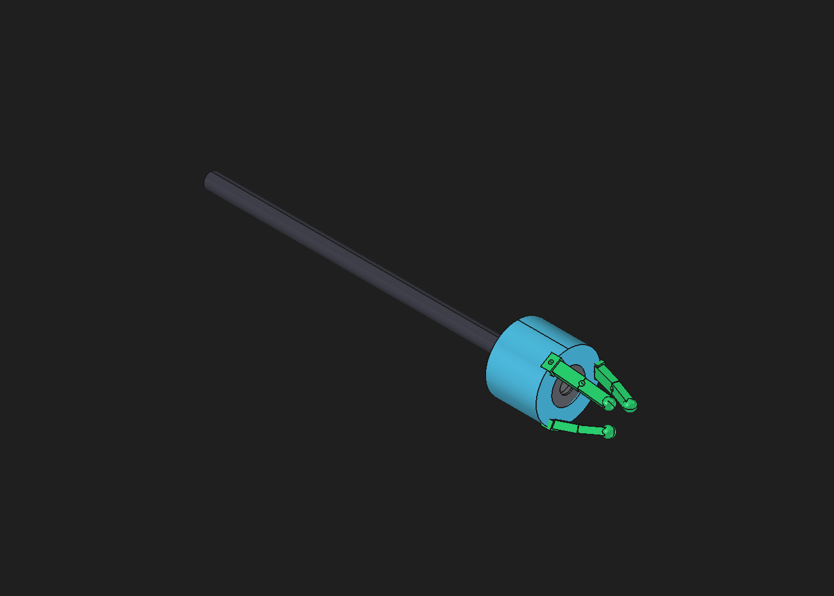
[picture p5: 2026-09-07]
cad/drawings/catcher_fingers_iso.png

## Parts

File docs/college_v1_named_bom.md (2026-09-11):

> **Print-CAD revision notice (2026-09-08):** This is the earlier candidate basket, not a purchase release matching the new development STLs. The current set slices to about 2.70 kg, exceeding its two-spool allowance. Printed spur gears and the two-link claw also require drive/fastener reconciliation. See the new print package README before ordering or bulk printing.

# College V1: named parts and maximum practical printing

This supersedes the earlier $705.64 allowance basket. That figure was not a
demonstrated minimum: it combined $547.86 of broadly estimated parts with $157.78
of shipping/tax and contingency. Its blanket metal-only recommendations for
bearing caps, belt clamps and small pulleys were too restrictive for this slow V1.

## Current cost

The revised 59-line candidate basket is **$368.47 in parts**. Allowing $45 shipping
and an illustrative 8% tax on parts plus shipping gives **$446.55 before repair
reserve**. An optional 15% repair/redesign reserve adds $66.98, giving **$513.53**.
Shipping is not a checkout quote and the tax rate is not a jurisdiction-specific
calculation. Seven lines totaling $109.52 have observed supplier prices; the
remaining named standard components/pack prices are explicitly estimates.

Parts divide into $40 filament, $57.52 motors/drivers/servo, $106 mechanical
hardware, $107.35 power/protection components, $45.60 control/sensing/wire, and
$12 assembly consumables/balls. No separate purchased shoulders, boom tubes,
pulley bodies, bearing caps, belt-clamp caps or large guard panels are charged.

The work Prusa has no printer-purchase charge. The exact model and usable bed size
are not confirmed. Two complete PETG spools remain in the cash list; slicing has
not established consumed mass. Work-supplied filament would remove $40 parts if
confirmed. Existing ESP32 and host PC are credited, but no unknown EE parts or
unidentified servo are silently credited. Access to ordinary hand tools, shaft
cutting and dimensional measurement is assumed; those tools are not in this parts
total. No camera, autonomous catching or throwing capability is included.

## Searchable items

`engineering/bom_college_v1.csv` now uses manufacturer part names or fully
specified commodity search names, rather than lines such as 'motion hardware'.
Quantity means purchase quantity: a ten-pack is counted as one pack, not as one
bearing. Pack contents and any unresolved fit are described in the specification.

Examples with observed prices on 8 September 2026:

- Three STEPPERONLINE **17HS19-2004S1** motors, $9.62 each:
  https://www.omc-stepperonline.com/nema-17-bipolar-59ncm-84oz-in-2a-42x48mm-4-wires-w-1m-cable-connector-17hs19-2004s1
- Three BIGTREETECH **TMC2209 V1.3**, SKU **1040000053**, $7.89 each:
  https://biqu.equipment/products/btt-tmc2209-stepper-driver
  The search excerpt showed an older $6.94; the opened current product page showed
  $7.89, which is the value used. No bulk or unearned coupon discount is assumed.
- MEAN WELL **GST60A12-P1J**, $19.40:
  https://www.bravoelectro.com/gst60a12-p1j.html
  The grounded C13 cord and appropriately rated barrel connector are separate.
- TowerPro **MG90S positional servo**, $4.99 listing:
  https://dfh.fm/products/mg90s-servo
  This is a candidate, not identification of the user's existing servo.
- Adafruit **6357 AS5600** sensors, $5.95 each:
  https://www.adafruit.com/product/6357
- Adafruit **2717 TCA9548A** multiplexer, $6.95:
  https://www.adafruit.com/product/2717
- Adafruit **819 roller microswitches**, $1.95 each:
  https://www.adafruit.com/product/819

Standard search names include **608-2RS 8x22x7 mm**, **625-2RS 5x16x5 mm**,
**400-2GT-6 timing belt**, **8 mm h6 ground shaft**, and metric fastener sizes.
These define commodity families; an estimated price does not imply that every
seller's material, pack contents or rating is interchangeable. The workbook keeps
the source/price-status column beside these entries.

## What becomes printed

The print list includes the base, yaw housing/turret, boxed shoulder/yoke,
inner/outer telescope shells, joint sleeves, rear plug, guide shoes, motor mounts,
all drive/idler pulley bodies, bearing caps, belt clamps/caps, collars/spacers,
hard-stop bodies, padded pitch catch cradle, friction-disk body, claw palm/fingers,
servo cradle/equalizer, sensor brackets, cable guides and guards.

The printed pulley design must use adequate tooth size and a split-clamp or D-flat
hub with mechanical axial retention. A metal grub screw in an unsupported printed
thread is not sufficient. Printed belt clamps use long toothed engagement and
steel through-bolts/locknuts. Printed bearing caps use broad annular ribs and
washers. Each is a fit/load-test candidate, not an automatic upgrade from metal.
The attached print manifest gives material/orientation/perimeter guidance and
explicitly labels its IDs as planned parts, not available released STL files.

Purchase actual bearings, smooth shafts, fasteners, small springs, reinforced
belts, line, friction/foam/PTFE facing, electronics and the small resistor heat
spreader. Printing these last items generally creates a large functional loss for
a small saving, or is not possible with an ordinary FDM printer. The goal is a
low-cost working demonstrator, not maximizing the printed percentage on paper.

## Changes enabling the lower estimate

The $60 external-driver allowance becomes $23.67 of named driver modules. Purchased
pulley/hub kits become $16 of belts plus printed bodies. The unnamed $35 brake
allowance becomes a candidate printed friction mechanism with purchased spring,
liner and preload bolt, backed by a padded catch cradle. The large supply becomes
a 12 V 60 W external adapter appropriate to investigating much slower, current-
limited operation. Guards and base structure move into the filament budget.

These are architecture changes, not equal-performance substitutions. The compact
scope remains roughly 350–550 mm reach, 200 mm stroke and light foam objects.
Loaded motor torque at the selected current/12 V, reduction ratio, printed tooth
life, telescope straightness, sensor mechanics and temperatures need engineering
qualification. The motor's 2 A/0.59 Nm holding rating is not credited at 1 A RMS.

The candidate friction restraint must hold worst-case gravity torque at maximum
extension and still leave enough motor torque to move against friction. Printed
worm gears are not assumed self-locking. A spring assortment is explicitly a
trial purchase; its exact rate has not been selected. If this approach fails,
the design and cost must be revised, not silently operated without restraint.

The new discrete relay/watchdog/overvoltage components are named circuit
candidates. Their schematic, threshold/hysteresis, startup state, motor cutoff,
inrush/DC contact rating, regeneration pulse rating and fault tests are unfinished.
The 12 V topology does not modify or energize the existing 24 V full-robot design.
Powering the ESP32 from host USB saves an extra regulator but requires correct
grounding and no 5 V backfeed. A listed relay does not make a certified safety system.

## Status

The BOM is now useful for looking up named candidates and challenging individual
prices. It is **not ready for ordering a complete compatible kit**: belt lengths,
spring/preload selection, screw grip lengths, compact CAD and the power/control
circuit still need closure. Existing full-size CAD/GIFs are preserved; they do not
depict this new printed compact robot. The higher-performance fair BOM remains
a separate unqualified proposal and has not been relabeled as this V1.

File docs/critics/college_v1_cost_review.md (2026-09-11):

# Independent compact V1 cost review — 8 September 2026

The independent critic agreed that a compact 350–550 mm reach V1 is plausible,
but rejected converting the current full-size arm to plastic as a major cost saving.
Their initial unitemized $280–420 parts envelope conflicted with the root's $547.86
line-item basket. On direct review of that basket, the critic withdrew the lower
estimate: no definite duplicate cost was found, and <=$420 was not defensible while
preserving powered yaw/pitch/extension/claw, feedback, pitch restraint and electrical
protection. Adopt $547.86 parts / $705.64 planning cash until specific reductions
are demonstrated. Do not average conflicting estimates or quote the optimistic one.

Major issues: unclear demonstration scope (high severity/high likelihood); long
printed boom joints and guide straightness (high/high); pitch collapse on power
loss (high/medium); unqualified actuator/ESP32 compatibility (high/high). Minor
issues include printer access and repair consumables (medium/medium), and
unproven upgrade reuse (medium/high). Retain shafts/bearings and wear components,
use shorter printed structures, and characterize fit before committing to a set.

The critic's independent favorable-to-ideal beam model at the current full length
estimated 0.339 mm aluminum inner-boom sag versus 9.39 mm for 3 mm-wall PETG using
1.5 GPa printed-coupon modulus, including inner-tube self-weight and catcher offset.
The root's uniform tip-load ratio uses a different supplier's higher 2.31 GPa XY
modulus and finds 18–19 times greater deflection at equal span. These are different
assumptions, not contradictory results; neither includes joints or creep and both
reject an equivalent-performance plastic substitution at the old span.

Compact V1 concept score: 5/10; not ready to order a full kit or manufacture.
Needs dedicated CAD, dimensional/actuator sizing and actual hardware interfaces.
Cheap fit coupons and isolated claw tests are the useful next prototype work.

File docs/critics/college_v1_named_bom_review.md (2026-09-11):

# Independent print-first BOM review

The earlier critic's $705.64 position applied to an insufficiently optimized
allowance basket; it was not proof of a minimum price. The subsequent independent
review identified overly restrictive metal-only caps/clamps/pulleys, unproven
$60 driver and $35 brake allowances, and vague feedback/protection entries.

Implemented response: named TMC2209 modules, printed drive/support bodies,
12 V slow-operation candidate power architecture, individually named discrete
protection components and a conditional printed friction/catch-cradle approach.

On re-review of the 59-line $368.47 basket, the critic found no high-priority
arithmetic or naming errors. Shipping/tax and optional reserve totals were
independently checked as $446.55 and $513.53. No obvious voltage mismatch was
identified at the BOM level. This is a bounded candidate-parts review, not a
complete electronics or mechanical approval.

Remaining findings: most prices are estimated commodity pack prices rather than
verified vendor listings; exact shaft/belt quantities depend on compact CAD;
12 V/derated-current running torque, printed friction hold, and dump circuit
capacity remain unverified. Keep all these distinctions in user-facing results.
The full-size fair design and its BOM are separate and unchanged by this review.

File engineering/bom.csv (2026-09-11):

item | qty | component | spec | unit_price_usd | ext_price_usd | stage | price_status | source_or_basis | purpose
1 | 1 | Outer aluminum tube | 6061-T6 1.5in square nominal0.0625in wall 36in stock | 26.1 | 26.1 | extension_rig | observed_2026-09-07 | https://www.onlinemetals.com/en/buy/aluminum/1-5-x-0-062-aluminum-square-tube-6061-t6-extruded/pid/26374 | 770mm cut length verify actual0.062in wall
2 | 1 | Inner aluminum tube | 6061-T6 1in square nominal0.0625in wall 36in stock | 22 | 22 | extension_rig | estimate_unquoted | US metric equivalent must be recalculated | 805mm cut length
3 | 1 | Extension motor encoder driver kit | NEMA17 closed loop exact part NOT SELECTED | 70 | 70 | extension_rig | estimate_unquoted | Running torque requirement at1000rpm unverified | Proximal drive
4 | 1 | Extension belt pulleys and bearings | 9mm GT2 belt; two36T metal pulleys; two625 bearings;5mm idler shaft collars; metal clamp cap | 30 | 30 | extension_rig | estimate_unquoted | Unquoted allowance; exact belt and pulley ratings pending;625 boundary dimensions5x16x5mm | Bidirectional internal drive run
5 | 1 | Guide wear stock and shims | Acetal wear stock for12 retained shoes plus clearance shims; printed fit coupons separate | 15 | 15 | extension_rig | estimate_unquoted | Small stock purchase | Six front and six rear replaceable wear shoes; do not budget an absent printed carrier
6 | 1 | Structural printing filament | 1kg PETG or ASA spool | 24 | 24 | extension_rig | estimate_unquoted | Full spool cash cost not grams used | Housings and fit coupons
7 | 1 | Standard fasteners and metal inserts | M2 M3 M4 M5 M6 M8 fasteners as applicable; washers locknuts inserts and smooth claw pins | 30 | 30 | extension_rig | estimate_unquoted | Pack-purchase allowance; includes24 M2x8 guide screws24 M2 nuts24 thin washers; exact remaining grip lengths pending CAD | Mechanical assembly
8 | 1 | Control board | Owned ESP32 exact board pending; current firmware target Teensy | 0 | 0 | extension_rig | user_owned_2026-09-07 | ESP32 firmware port and board-specific timing/pin verification required | Real-time firmware board
9 | 1 | Motor power supply | 24V350W class 14.6A candidate with AC enclosure | 45 | 45 | extension_rig | estimate_unquoted | https://www.meanwell.com/Upload/PDF/LRS-350/LRS-350-SPEC.PDF | Shared machine power supply
10 | 1 | DC logic regulator | 24V to5V filtered buck plus input protection | 10 | 10 | extension_rig | estimate_unquoted | Confirm input transients | MCU and sensor power
11 | 1 | Limit and home switch kit | Four NC switches brackets and wire | 10 | 10 | extension_rig | estimate_unquoted | Switch currents and logic compatibility to be selected | Homing and end limits
12 | 1 | Extension rig restraint and bumpers | Bench restraint; four5mm steel stop pins and metal retaining caps; printed split collars and keyed TPU pads | 22 | 22 | extension_rig | estimate_unquoted | Unquoted allowance; printed parts use filament lines; single-pin impact proof required | Restrained test setup
13 | 1 | Hardware E-stop controls | Mushroom NC contacts manual reset and monitor wiring | 15 | 15 | shared_safety | estimate_unquoted | Not a safety-certified complete control system | Independent stop request
14 | 1 | DC-rated contactor | Fuse-coordinated motor-bus interruption candidate | 25 | 25 | shared_safety | estimate_unquoted | DC interrupt rating must match selected bus | Motor power removal
15 | 1 | Regeneration clamp circuit | Overvoltage chopper plus pulse rated resistor and housing | 30 | 30 | shared_safety | estimate_unquoted | Design not yet released | Absorb motor regeneration
16 | 1 | Power wiring and connectors | 16AWG trunk 18AWG short branches shielded feedback connector kit | 25 | 25 | shared_safety | estimate_unquoted | Current ratings and flex life to verify | Power and signal harness
17 | 1 | Fuses holders mains enclosure | Fused inlet protective earth insulated terminals enclosure | 20 | 20 | shared_safety | estimate_unquoted | Mains assembly needs competent verification | AC and DC protection
18 | 1 | Logic interface carrier | Encoder receivers optocouplers fault inputs current monitor | 18 | 18 | shared_safety | estimate_unquoted | No unprotected5V into3.3V MCU | Driver and sensor integration
19 | 2 | Yaw and pitch motor driver kits | 1-CL57T-P20-V41 candidate2Nm holding exact running curve unqualified | 86.6 | 173.2 | rotating_axes | observed_2026-09-07 | https://www.omc-stepperonline.com/tp-series-1-axis-closed-loop-stepper-cnc-kit-2-0nm-283-28oz-in-nema-23-motor-driver-1-cl57t-p20-v41 | Price reference not approved highspeed selection
20 | 1 | Pitch reduction hardware | Two-stage HTD5 20to40 plus20to80 shafts bearings hubs belt | 45 | 45 | rotating_axes | estimate_unquoted | Belt kit allowance includes metal hubs small pulleys and jackshaft parts; large printed pulley web uses filament line; excludes separately listed6001 bearings | 8to1 candidate reduction
21 | 1 | Yaw reduction hardware | Two-stage HTD5 20to30 plus20to80 shafts bearings hubs belt | 40 | 40 | rotating_axes | estimate_unquoted | Two staged belts metal small pulleys and hubs; large printed pulley web uses filament line; excludes separately listed6001 bearings | 6to1 candidate reduction matched to full CAD
22 | 1 | Pitch brake and hold-up | Failsafe normally engaged brake controller energy reserve | 45 | 45 | rotating_axes | estimate_unquoted | Exact brake and belt-break retention remain gates | Prevent gravity drop after power loss
23 | 6 | Pitch and jackshaft bearings | 6001-2RS class12mm bore | 3 | 18 | rotating_axes | estimate_unquoted | Manufacturer static dynamic speed ratings required | Pitch trunnions and both compound drive shafts
24 | 1 | Shafts collars hubs and spacers | 12mm steel short trunnions plus20mm yaw shaft and collar hardware | 38 | 38 | rotating_axes | estimate_unquoted | Ground shaft stock proper axial retention; full CAD rebaseline | Load-bearing purchased hardware
25 | 1 | Frame stock and bench anchor | 850mm shoulder with windowed3mm cheeks and stock-angle stiffeners; column braces base | 80 | 80 | rotating_axes | estimate_unquoted | Unquoted stock allowance including raised shoulder; no outsourced machining | Mount stiffness and anti-tip restraint
26 | 1 | Independent output feedback | Two axis output sensors plus extension position reference | 30 | 30 | rotating_axes | estimate_unquoted | Driver motor encoders cannot detect slipped belt or hub | Load-side state verification
27 | 1 | TPU printing filament | 1kg95A spool full cash purchase | 24 | 24 | claw | estimate_unquoted | Use coupons to establish impact stroke | Compliant contact pads and bumpers; rigid claw fingers use structural filament
28 | 1 | Claw actuation and hardware | Small metal gear servo links spring pins breakbeam cable | 20 | 20 | claw | estimate_unquoted | Unknown owned servo not yet credited; exact model torque speed travel and current pending; includes metal pins springs tendons retainers | Retention and release
29 | 1 | Soft practice balls | Specified50g or lighter foam balls batch | 10 | 10 | claw | estimate_unquoted | Weigh every tested ball type | Impact tests
30 | 2 | Cameras | Matched60to120fps low latency cameras candidate | 40 | 80 | vision | estimate_unquoted | No verified stereo sync or latency yet | 3D perception
31 | 1 | Vision accessories | Calibration target mounts powered USB hub cables | 20 | 20 | vision | estimate_unquoted | Existing host PC assumed | Camera integration
32 | 1 | Guard enclosure materials | Polycarbonate mesh frame and fasteners allowance | 40 | 40 | shared_safety | estimate_unquoted | Not optional for highspeed tests | Segregated test workspace
33 | 1 | Consumables | Adhesive threadlocker solder heatshrink tie mounts | 15 | 15 | extension_rig | estimate_unquoted | Full purchase allowance | Assembly and repair
34 | 2 | Yaw shaft bearings | 6204 class20x47x14mm | 4 | 8 | rotating_axes | estimate_unquoted | Full CAD paired20mm yaw bearing envelopes; exact rated SKU pending | Yaw bearing separation and axial retention
35 | 1 | Claw power regulator | Separate filtered5to6V buck sized for measured servo peak current | 8 | 8 | claw | estimate_unquoted | Planning allowance not selected hardware; bus input voltage and servo rail required; no MCU3.3V servo supply | Isolate servo current pulses from MCU rail with common reference and local bulk capacitance

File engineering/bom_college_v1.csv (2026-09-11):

item | qty | component | spec | unit_price_usd | ext_price_usd | stage | price_status | source_or_basis | purpose
1 | 2 | SUNLU PETG 1.75 mm filament — 1 kg spool | Two retail spools including trial prints; no bulk-order discount assumed | 20 | 40 | printing | estimate_unquoted | https://store.sunlu.com/collections/petg | Compact V1; quantity/fit to be checked against final CAD
2 | 3 | STEPPERONLINE 17HS19-2004S1 NEMA17 motor | 42x42x48 mm; 5 mm D-shaft; 2 A rated phase current; V1 uses derated current | 9.62 | 28.86 | motion | observed_2026-09-08 | https://www.omc-stepperonline.com/nema-17-bipolar-59ncm-84oz-in-2a-42x48mm-4-wires-w-1m-cable-connector-17hs19-2004s1 | Yaw pitch extension; 0.59 Nm holding rating is NOT operating torque
3 | 3 | BIGTREETECH TMC2209 V1.3 — SKU 1040000053 | 1PC option each; STEP/DIR plus UART; 12 V bus; start <=1 A RMS only after sizing | 7.89 | 23.67 | motion | observed_2026-09-08 | https://biqu.equipment/products/btt-tmc2209-stepper-driver | Carrier thermal/current settings and firmware integration pending
4 | 1 | TowerPro MG90S positional micro servo | 180-degree positional version with supplied horn; NOT continuous rotation | 4.99 | 4.99 | motion | observed_2026-09-08 | https://dfh.fm/products/mg90s-servo | Candidate claw servo; unknown owned servo not credited; force/travel test required
5 | 2 | 400-2GT-6 closed-loop timing belt | 400 mm pitch length; 2 mm pitch; 6 mm wide; 200 teeth | 3 | 6 | mechanical | estimate_unquoted | Search the exact component name; pack price estimate, not a checked listing | Tentative yaw and first pitch stage lengths; do not order until center distances are fixed
6 | 1 | 600-2GT-6 closed-loop timing belt | 600 mm pitch length; 2 mm pitch; 6 mm wide; 300 teeth | 4 | 4 | mechanical | estimate_unquoted | Search the exact component name; pack price estimate, not a checked listing | Tentative second pitch stage; CAD center distance pending
7 | 1 | 2GT-6 open timing belt — 2 metre roll | 2 mm pitch; 6 mm wide; fiberglass reinforced rubber; NOT steel cord | 6 | 6 | mechanical | estimate_unquoted | Search the exact component name; pack price estimate, not a checked listing | Telescope; printed toothed clamps and printed pulleys
8 | 1 | 608-2RS bearings 8x22x7 mm — 10 pack | Standard steel radial ball bearings; use measured fits; no premium ABEC claim needed | 12 | 12 | mechanical | estimate_unquoted | Search the exact component name; pack price estimate, not a checked listing | Compact V1; quantity/fit to be checked against final CAD
9 | 1 | 625-2RS bearings 5x16x5 mm — 10 pack | Steel radial ball bearings; idler and small shaft supports; spare inventory included | 8 | 8 | mechanical | estimate_unquoted | Search the exact component name; pack price estimate, not a checked listing | Compact V1; quantity/fit to be checked against final CAD
10 | 2 | 8 mm h6 ground steel shaft — 300 mm length | Cut for pitch yaw and compound shafts; printed collars with steel retention hardware | 5 | 10 | mechanical | estimate_unquoted | Search the exact component name; pack price estimate, not a checked listing | Compact V1; quantity/fit to be checked against final CAD
11 | 1 | 5 mm ground steel shaft — 200 mm length | Cut idler shafts and smooth pins; bearings run on smooth shaft | 4 | 4 | mechanical | estimate_unquoted | Search the exact component name; pack price estimate, not a checked listing | Compact V1; quantity/fit to be checked against final CAD
12 | 1 | M3 socket-head screw nut washer assortment | Metric steel M3x8/12/16/20/25/30; M3 nuts and washers; 200-piece class pack | 9 | 9 | mechanical | estimate_unquoted | Search the exact component name; pack price estimate, not a checked listing | Compact V1; quantity/fit to be checked against final CAD
13 | 1 | M4 socket-head screw nut washer assortment | Metric steel M4x10/16/20/25/30/40; nuts and washers; 150-piece class pack | 10 | 10 | mechanical | estimate_unquoted | Search the exact component name; pack price estimate, not a checked listing | Compact V1; quantity/fit to be checked against final CAD
14 | 1 | M5x60 bolt M5 locknut and M5 washers — 10 sets | Prototype friction adjustment and attachment; shaft load path stays metal | 4 | 4 | mechanical | estimate_unquoted | Search the exact component name; pack price estimate, not a checked listing | Compact V1; quantity/fit to be checked against final CAD
15 | 1 | 0.13 mm PTFE adhesive tape — 10 mm x 5 m | Replaceable low-friction facing on printed guide shoes; inspect peel and adhesive creep | 5 | 5 | mechanical | estimate_unquoted | Search the exact component name; pack price estimate, not a checked listing | Compact V1; quantity/fit to be checked against final CAD
16 | 1 | Cork-rubber gasket sheet — 1 mm x 150 x 150 mm | Cut friction pads; mechanical retention; friction coefficient requires test | 4 | 4 | mechanical | estimate_unquoted | Search the exact component name; pack price estimate, not a checked listing | Compact V1; quantity/fit to be checked against final CAD
17 | 1 | Steel compression/extension spring assortment — 200-piece pack | Trial preload and claw springs; exact spring rate is NOT selected | 7 | 7 | mechanical | estimate_unquoted | Search the exact component name; pack price estimate, not a checked listing | Assortment for experimentation, not final spring specification
18 | 1 | Braided UHMWPE fishing line — 0.5 mm x 10 m | Claw tendon and sensor line; knot and abrasion test needed | 4 | 4 | mechanical | estimate_unquoted | Search the exact component name; pack price estimate, not a checked listing | Compact V1; quantity/fit to be checked against final CAD
19 | 2 | 50 mm steel C-clamp | Clamp printed base to rigid bench; verify throat fits actual bench | 3 | 6 | mechanical | estimate_unquoted | Search the exact component name; pack price estimate, not a checked listing | Compact V1; quantity/fit to be checked against final CAD
20 | 1 | 3 mm braided polyester cord — 5 m | Independent short retention tether; not a substitute for a qualified pitch restraint | 3 | 3 | mechanical | estimate_unquoted | Search the exact component name; pack price estimate, not a checked listing | Compact V1; quantity/fit to be checked against final CAD
21 | 1 | Closed-cell EVA foam sheet — 5 mm x 200 x 300 mm | Claw contact pads and padded catch cradle; not a proven impact absorber | 4 | 4 | mechanical | estimate_unquoted | Search the exact component name; pack price estimate, not a checked listing | Compact V1; quantity/fit to be checked against final CAD
22 | 1 | MEAN WELL GST60A12-P1J power adapter | 12 V 5 A 60 W; 5.5x2.1 mm center-positive plug; external enclosed supply | 19.4 | 19.4 | power | observed_2026-09-08 | https://www.bravoelectro.com/gst60a12-p1j.html | 12 V compact V1 only; simultaneous load/regen tests pending; tariffs may apply
23 | 1 | NEMA 5-15P to IEC C13 grounded power cord — 1.8 m | Listed cord for adapter; computers owned does not imply spare cord owned | 5 | 5 | power | estimate_unquoted | Search the exact component name; pack price estimate, not a checked listing | Compact V1; quantity/fit to be checked against final CAD
24 | 1 | 5.5x2.1 mm DC barrel female pigtail — 18 AWG | Require documented >=5 A rating; avoid tiny unmarked screw-terminal adapter | 3 | 3 | power | estimate_unquoted | Search the exact component name; pack price estimate, not a checked listing | Compact V1; quantity/fit to be checked against final CAD
25 | 1 | Adafruit 1385 UBEC 5 V 3 A buck converter | Servo rail from switched 12 V bus; verify peak current and actual pin polarity | 9.95 | 9.95 | power | estimate_unquoted | https://www.adafruit.com/product/1385 | ESP32 uses existing host USB; common ground, no backfeeding USB 5 V
26 | 1 | Owned ESP32 development board | Exact board/model pending; existing USB-powered host connection | 0 | 0 | control | user_owned | User reported owned | Board-specific firmware port and pin verification required
27 | 3 | Adafruit 6357 AS5600 magnetic angle sensor | STEMMA QT breakout; solder headers; supply 3.3 V for ESP32 interface | 5.95 | 17.85 | control | observed_2026-09-08 | https://www.adafruit.com/product/6357 | Yaw/pitch output sensing; extension sensing mechanism still to be finalized
28 | 1 | Adafruit 2717 TCA9548A I2C multiplexer | Separate channels for three fixed-address AS5600 sensors | 6.95 | 6.95 | control | observed_2026-09-08 | https://www.adafruit.com/product/2717 | Use short soldered wiring rather than extra QT cable purchases
29 | 1 | 6x2.5 mm diametrically magnetized NdFeB disc — 5 pack | DIAMETRIC magnetization; axial magnetization is not interchangeable | 4 | 4 | control | estimate_unquoted | Search the exact component name; pack price estimate, not a checked listing | Compact V1; quantity/fit to be checked against final CAD
30 | 4 | Adafruit 819 roller-lever microswitch | COM/NC wiring; pitch yaw home plus telescope home/end; software bounds elsewhere | 1.95 | 7.8 | control | observed_2026-09-08 | https://www.adafruit.com/product/819 | Logic switching only; not motor-bus current
31 | 1 | XB2-BS542 22 mm latching mushroom switch — 1NC | Twist-release red button with NC contact block; prototype part, not safety-system certification | 8 | 8 | power | estimate_unquoted | Search the exact component name; pack price estimate, not a checked listing | Interrupt low-current relay-coil path independently of MCU; printed enclosure
32 | 2 | Omron G5LE-14 DC12 PCB relay | 12 V coil SPDT; two relays budgeted for manual-reset/interlock development | 2.5 | 5 | power | estimate_unquoted | https://omronfs.omron.com/en_US/ecb/products/pdf/en-g5le.pdf | Exact DC load/inrush coordination and circuit proof required
33 | 1 | 6x6 mm through-hole tactile switch — 10 pack | Momentary manual reset buttons | 1.5 | 1.5 | power | estimate_unquoted | Search the exact component name; pack price estimate, not a checked listing | Compact V1; quantity/fit to be checked against final CAD
34 | 1 | 2N7000 TO-92 MOSFET — 10 pack | Relay-coil and logic gating experiments; never drive motor phase current | 2 | 2 | power | estimate_unquoted | Search the exact component name; pack price estimate, not a checked listing | Compact V1; quantity/fit to be checked against final CAD
35 | 1 | 1N4007 rectifier diode — 20 pack | Coil suppression; release delay must be checked | 1.5 | 1.5 | power | estimate_unquoted | Search the exact component name; pack price estimate, not a checked listing | Compact V1; quantity/fit to be checked against final CAD
36 | 1 | 74HC123N retriggerable monostable DIP-16 — 2 pack | Hardware heartbeat timeout prototype; timing RC parts below | 2 | 2 | power | estimate_unquoted | Search the exact component name; pack price estimate, not a checked listing | Compact V1; quantity/fit to be checked against final CAD
37 | 1 | SN74HC14N Schmitt-trigger inverter DIP-14 — 2 pack | Condition switch/heartbeat signals at 3.3 V | 2 | 2 | power | estimate_unquoted | Search the exact component name; pack price estimate, not a checked listing | Compact V1; quantity/fit to be checked against final CAD
38 | 1 | LM393P dual comparator DIP-8 — 5 pack | Candidate overvoltage dump controller; circuit not released | 2 | 2 | power | estimate_unquoted | Search the exact component name; pack price estimate, not a checked listing | Compact V1; quantity/fit to be checked against final CAD
39 | 1 | TL431CLP adjustable shunt reference TO-92 — 5 pack | Candidate bus threshold reference | 1.5 | 1.5 | power | estimate_unquoted | Search the exact component name; pack price estimate, not a checked listing | Compact V1; quantity/fit to be checked against final CAD
40 | 1 | IRLZ44NPBF logic MOSFET TO-220 — 2 pack | Candidate dump switch; gate drive/thermal qualification required | 3 | 3 | power | estimate_unquoted | Search the exact component name; pack price estimate, not a checked listing | Compact V1; quantity/fit to be checked against final CAD
41 | 1 | 47 ohm 25 W aluminum-housed wirewound resistor | Pulse-energy-rated part required; mount on small metal heat spreader, not plastic | 4 | 4 | power | estimate_unquoted | Search the exact component name; pack price estimate, not a checked listing | Candidate bus dump load; threshold/duty and pulse rating remain a design gate
42 | 1 | 50x50x2 mm aluminum plate | Heat spreader for dump resistor; small purchased thermal part | 2 | 2 | power | estimate_unquoted | Search the exact component name; pack price estimate, not a checked listing | Compact V1; quantity/fit to be checked against final CAD
43 | 1 | 470 uF 35 V 105C low-ESR radial capacitor — 5 pack | Local motor-bus decoupling; minimum ripple rating to verify | 3 | 3 | power | estimate_unquoted | Search the exact component name; pack price estimate, not a checked listing | Compact V1; quantity/fit to be checked against final CAD
44 | 1 | 1000 uF 10 V 105C radial capacitor — 5 pack | Servo-rail local bulk capacitance | 2 | 2 | power | estimate_unquoted | Search the exact component name; pack price estimate, not a checked listing | Compact V1; quantity/fit to be checked against final CAD
45 | 1 | 100 nF 50 V X7R ceramic capacitor — 50 pack | Local IC bypass | 1.5 | 1.5 | power | estimate_unquoted | Search the exact component name; pack price estimate, not a checked listing | Compact V1; quantity/fit to be checked against final CAD
46 | 1 | 1 uF film capacitor — 10 pack | Heartbeat timing experiments; tolerance needed for timeout | 2 | 2 | power | estimate_unquoted | Search the exact component name; pack price estimate, not a checked listing | Compact V1; quantity/fit to be checked against final CAD
47 | 1 | 1% metal-film resistor assortment 1/4 W — E12 kit | Includes 1k 4.7k 10k 47k 100k; threshold/timing values may require additional E96 values | 4 | 4 | power | estimate_unquoted | Search the exact component name; pack price estimate, not a checked listing | Compact V1; quantity/fit to be checked against final CAD
48 | 1 | 5x7 cm FR4 plated perfboard — 5 pack | Soldered driver carrier and interface circuit; no motor current through solderless breadboard | 4 | 4 | power | estimate_unquoted | Search the exact component name; pack price estimate, not a checked listing | Compact V1; quantity/fit to be checked against final CAD
49 | 1 | 2.54 mm female header 1x40 — 10 pack | Driver sockets; split to fit; verify contact current rating | 3 | 3 | power | estimate_unquoted | Search the exact component name; pack price estimate, not a checked listing | Compact V1; quantity/fit to be checked against final CAD
50 | 1 | KF301-2P 5.08 mm screw terminal — 10 pack | PCB terminals; select rated supplier part for bus current | 3 | 3 | power | estimate_unquoted | Search the exact component name; pack price estimate, not a checked listing | Compact V1; quantity/fit to be checked against final CAD
51 | 1 | Inline mini-blade fuse holder 18 AWG — 3 pack | Branch/bus fusing; actual fuse selection depends on load and interrupt rating | 4 | 4 | power | estimate_unquoted | Search the exact component name; pack price estimate, not a checked listing | Compact V1; quantity/fit to be checked against final CAD
52 | 1 | 32 V mini-blade fuse assortment 1/2/3/5 A — 20 pack | Candidate fuse inventory; do not install maximum rating by default | 3 | 3 | power | estimate_unquoted | Search the exact component name; pack price estimate, not a checked listing | Compact V1; quantity/fit to be checked against final CAD
53 | 1 | 18 AWG stranded copper wire red/black — 5 m pair | Short motor/power branches; copper, not CCA | 6 | 6 | power | estimate_unquoted | Search the exact component name; pack price estimate, not a checked listing | Compact V1; quantity/fit to be checked against final CAD
54 | 1 | 24 AWG stranded hookup wire — six colours 2 m each | Switches encoders logic wiring | 5 | 5 | control | estimate_unquoted | Search the exact component name; pack price estimate, not a checked listing | Compact V1; quantity/fit to be checked against final CAD
55 | 1 | JST-XH 2.54 mm precrimped pigtail kit 2/3/4 pin | Signal connectors; do not assume motor power capability | 4 | 4 | control | estimate_unquoted | Search the exact component name; pack price estimate, not a checked listing | Compact V1; quantity/fit to be checked against final CAD
56 | 1 | Polyolefin heat-shrink tubing assortment — 100 pieces | Insulation and strain-relief finishing | 3 | 3 | assembly | estimate_unquoted | Search the exact component name; pack price estimate, not a checked listing | Compact V1; quantity/fit to be checked against final CAD
57 | 1 | 2.5x100 mm nylon cable ties — 100 pack | Wire restraint | 2 | 2 | assembly | estimate_unquoted | Search the exact component name; pack price estimate, not a checked listing | Compact V1; quantity/fit to be checked against final CAD
58 | 1 | Removable medium-strength threadlocker — 5 ml | Metal-to-metal threads only; verify plastic compatibility | 3 | 3 | assembly | estimate_unquoted | Search the exact component name; pack price estimate, not a checked listing | Compact V1; quantity/fit to be checked against final CAD
59 | 1 | 40–50 mm soft foam practice ball — 6 pack | Weigh; <=20 g V1 target; no throwing release | 4 | 4 | assembly | estimate_unquoted | Search the exact component name; pack price estimate, not a checked listing | Compact V1; quantity/fit to be checked against final CAD

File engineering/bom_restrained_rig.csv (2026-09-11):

item | qty | component | spec | unit_price_usd | ext_price_usd | stage | price_status | source_or_basis | purpose
1 | 1 | Outer tube | 36in stock1.5in square6061 | 26.1 | 26.1 | rig | observed_2026-09-07 | Same source as full BOM | 770mm cut
2 | 1 | Inner tube | 36in stock1in square6061 | 22 | 22 | rig | estimate_unquoted | Local stock quote needed | 805mm cut
3 | 1 | Economy42mm closed-loop motor and driver | Candidate integrated encoder controller with hardware enable and fault output | 45 | 45 | rig | estimate_unquoted | Exact kit supplier thermal and fault behavior still a gate | Single-axis low-speed characterization
4 | 1 | Belt transmission kit | 9mm GT2 belt; two36T metal pulleys; two625 bearings;5mm idler shaft collars; metal clamp cap | 30 | 30 | rig | estimate_unquoted | Unquoted allowance; exact belt and pulley ratings pending;625 boundary dimensions5x16x5mm | Low-speed extension
5 | 1 | Wear strip and shims | Acetal wear stock for12 retained shoes plus clearance shims; printed fit coupons separate | 12 | 12 | rig | estimate_unquoted | Small stock purchase | Six front and six rear replaceable wear shoes; do not budget an absent printed carrier
6 | 1 | PETG filament | Full1kg spool | 20 | 20 | rig | estimate_unquoted | Full spool cash price | Guide and claw housing fit parts
7 | 1 | TPU filament | Full1kg spool | 22 | 22 | rig | estimate_unquoted | Full spool cash price | Compliant contact pads and bumpers; rigid claw fingers use structural filament
8 | 1 | Fasteners and inserts | M2 M3 M4 M5 M6 M8 fasteners as applicable; washers locknuts inserts and smooth claw pins | 23 | 23 | rig | estimate_unquoted | Pack-purchase allowance; includes24 M2x8 guide screws24 M2 nuts24 thin washers; exact remaining grip lengths pending CAD | Assembly
9 | 1 | Rig microcontroller | Owned ESP32 exact board pending | 0 | 0 | rig | user_owned_2026-09-07 | Requires ESP32 firmware port and hardware verification; current target Teensy | Deterministic low-speed steps and watchdog
10 | 1 | External motor supply | Enclosed approved24V60W adapter candidate | 35 | 35 | rig | estimate_unquoted | Exact adapter load transient and approvals must be verified | No exposed mains assembly in rig
11 | 1 | Limit switches | Two NC home and end contacts with brackets | 6 | 6 | rig | estimate_unquoted | Proof wiring behavior before movement | Stroke limits
12 | 1 | E-stop | NC mushroom with manual reset | 12 | 12 | rig | estimate_unquoted | Independent hardware cutoff circuit | User stop
13 | 1 | DC cutoff hardware | DC-rated relay or switch for24V2.5A plus suppressor | 12 | 12 | rig | estimate_unquoted | Rating verified before use not automotive assumption | Motor power interruption
14 | 1 | Fuse wiring and connectors | Small branch fuse holder shielded feedback and power wire | 16 | 16 | rig | estimate_unquoted | Appropriate DC ratings and strain relief | Protected rig harness
15 | 1 | Regeneration protection | Low-energy bus clamp and pulse resistor | 20 | 20 | rig | estimate_unquoted | Rig speed capped0.15mps horizontal | Protect driver downstream of cutoff
16 | 1 | Logic interfaces | Driver logic level interface and fault readback | 10 | 10 | rig | estimate_unquoted | Board compatibility to verify | Hardware enable and telemetry
17 | 1 | Claw mechanism hardware | Single microservo three springs tendons pins and retainers | 16 | 16 | rig | estimate_unquoted | Unknown owned servo not yet credited; exact model torque speed travel and current pending; includes metal pins springs tendons retainers | No net three-finger claw
18 | 1 | Fixture and end stops | Bench restraint; four5mm steel stop pins and metal retaining caps; printed split collars and keyed TPU pads | 22 | 22 | rig | estimate_unquoted | Unquoted allowance; printed parts use filament lines; single-pin impact proof required | Horizontal restrained fixture
19 | 1 | Rig guard | Local rigid tube and belt guard stock | 15 | 15 | rig | estimate_unquoted | Local low-speed single-axis containment not fullrobot guard | Pinch protection
20 | 1 | Foam balls | Small low-mass practice ball set | 6 | 6 | rig | estimate_unquoted | Weigh and characterize | Low-height claw drop tests
21 | 1 | Consumables | Solder heatshrink tie points threadlocker | 8 | 8 | rig | estimate_unquoted | Small purchase allowance | Rig build
22 | 1 | Claw power regulator | Separate filtered5to6V buck sized for measured servo peak current | 8 | 8 | rig | estimate_unquoted | Planning allowance not selected hardware; bus input voltage and servo rail required; no MCU3.3V servo supply | Isolate servo current pulses from MCU rail with common reference and local bulk capacitance

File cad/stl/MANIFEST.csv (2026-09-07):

file | qty | material | notes
PitchCheek_L.stl | 1 | PETG | Bearing pocket + NEMA23 + M4 inserts
PitchCheek_R.stl | 1 | PETG | Identical to L; mirror in assembly
NEMA23_MountPlate.stl | 2 | PETG | Extra motor plates (yaw/pitch)
NEMA17_MountPlate.stl | 1 | PETG | Extension motor
YawHubClamp.stl | 1 | PETG | Fits over yaw tube; check ID to stock
Guide_1.stl | 1 | Nylon or PETG | UHMW tape ID after print
Guide_2.stl | 1 | Nylon or PETG | UHMW tape ID after print
ExtensionStop_Min.stl | 1 | PETG | Retract bumper
ExtensionStop_Max.stl | 1 | PETG | Extend bumper
CableGuide.stl | 3 | PETG | Print 3 from one STL
CatcherHub.stl | 1 | PETG | Clamp on CF inner tip
CatcherAdapter.stl | 1 | PETG | Behind hub on inner tube
CatcherFunnel.stl | 1 | TPU 95A | Soft entrance
CatcherCradle.stl | 1 | TPU 95A | Soft backstop
CatcherRib.stl | 3 | PETG | Print 3
CatcherFinger.stl | 3 | PETG | Print 3; Ø6 pins
CatcherTipPad.stl | 3 | TPU 95A | Print 3; glue/slip on tips
HingePin.stl | 6 | PETG | 2 pins × 3 claws (or use steel dowel)
BaseFootSpacer.stl | 4 | PETG | Optional under leveling feet
ElectronicsEnclosure.stl | 1 | PETG | Hollow box + insert posts
ElectronicsEnclosure_Lid.stl | 1 | PETG | M3 screw-down lid

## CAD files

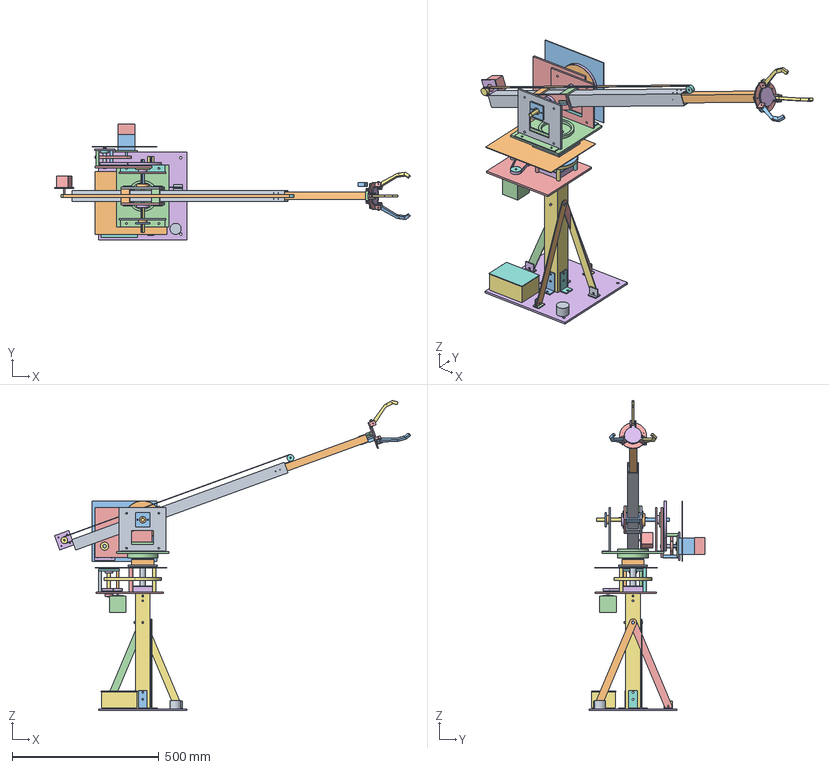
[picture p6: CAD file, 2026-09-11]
cad/review_b/VariableReachArm_Full_RevB.FCStd
1212.6 x 395.0 x 1056.4 mm
OuterTube
InnerTube
FrontSidePad_0
FrontFacePad_0_0
FrontFacePad_0_20
FrontSidePad_2
FrontFacePad_2_0
FrontFacePad_2_20
RearSidePad_0
RearFacePad_0_0
RearFacePad_0_20
RearSidePad_2
RearFacePad_2_0
RearFacePad_2_20
DrivePulleyPitchEnvelope
IdlerPulleyPitchEnvelope
BeltInsideEnvelope
BeltReturnEnvelope
CatcherClamp_bottom
CatcherClamp_top
GripperPalm
PalmContactPad
Claw_1
ClawPin_1
ClawSpacer_1_L
ClawSpacer_1_R
Claw_2
ClawPin_2
ClawSpacer_2_L
ClawSpacer_2_R
Claw_3
ClawPin_3
ClawSpacer_3_L
ClawSpacer_3_R
GripperServoEnvelope
CatcherStrut_0
CatcherStrut_2
BasePlate300x300x6
Column50x50x2
ColumnFootAngle_0
ColumnFootAngle_1
ColumnFootAngle_2
ColumnFootAngle_3
ColumnDiagonalBrace_0
BraceUpperBolt_0
BraceFootAngle_0
ColumnDiagonalBrace_1
BraceUpperBolt_1
BraceFootAngle_1
ColumnDiagonalBrace_2
BraceUpperBolt_2
BraceFootAngle_2
ColumnDiagonalBrace_3
BraceUpperBolt_3
BraceFootAngle_3
ColumnCrushSleeve_38
ColumnCrushSleeve_62
ColumnCrushSleeve_300
ColumnCrushSleeve_374
ColumnCrushSleeve_390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

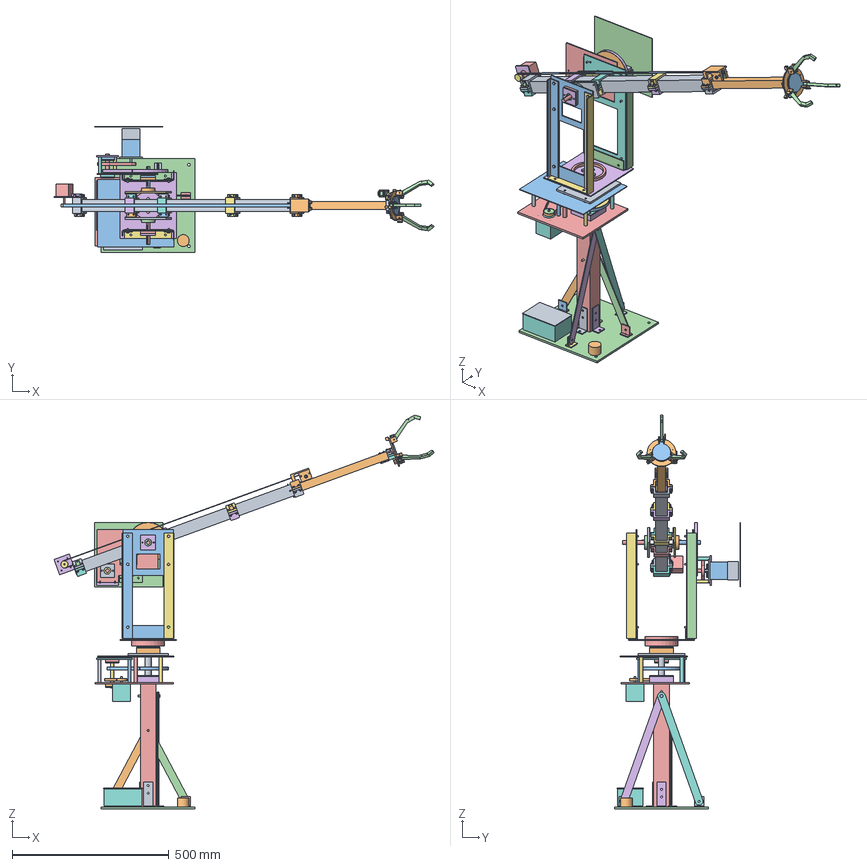
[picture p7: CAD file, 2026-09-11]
VariableReachArm_Full_RevB.FCStd
1212.6 x 402.0 x 1256.4 mm
OuterTube
InnerTube
FrontShoe_0__8
FrontShoe_0__8_Screw_0
FrontShoe_0__8_Washer_0
FrontShoe_0__8_Nut_0
FrontShoe_0__8_Screw_1
FrontShoe_0__8_Washer_1
FrontShoe_0__8_Nut_1
FrontShoe_0_8
FrontShoe_0_8_Screw_0
FrontShoe_0_8_Washer_0
FrontShoe_0_8_Nut_0
FrontShoe_0_8_Screw_1
FrontShoe_0_8_Washer_1
FrontShoe_0_8_Nut_1
FrontShoe_180__8
FrontShoe_180__8_Screw_0
FrontShoe_180__8_Washer_0
FrontShoe_180__8_Nut_0
FrontShoe_180__8_Screw_1
FrontShoe_180__8_Washer_1
FrontShoe_180__8_Nut_1
FrontShoe_180_8
FrontShoe_180_8_Screw_0
FrontShoe_180_8_Washer_0
FrontShoe_180_8_Nut_0
FrontShoe_180_8_Screw_1
FrontShoe_180_8_Washer_1
FrontShoe_180_8_Nut_1
FrontShoe_90_0
FrontShoe_90_0_Screw_0
FrontShoe_90_0_Washer_0
FrontShoe_90_0_Nut_0
FrontShoe_90_0_Screw_1
FrontShoe_90_0_Washer_1
FrontShoe_90_0_Nut_1
FrontShoe_270_0
FrontShoe_270_0_Screw_0
FrontShoe_270_0_Washer_0
FrontShoe_270_0_Nut_0
FrontShoe_270_0_Screw_1
FrontShoe_270_0_Washer_1
FrontShoe_270_0_Nut_1
RearShoe_0__8
RearShoe_0__8_Screw_0
RearShoe_0__8_Washer_0
RearShoe_0__8_Nut_0
RearShoe_0__8_Screw_1
RearShoe_0__8_Washer_1
RearShoe_0__8_Nut_1
RearShoe_0_8
RearShoe_0_8_Screw_0
RearShoe_0_8_Washer_0
RearShoe_0_8_Nut_0
RearShoe_0_8_Screw_1
RearShoe_0_8_Washer_1
RearShoe_0_8_Nut_1
RearShoe_180__8
RearShoe_180__8_Screw_0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

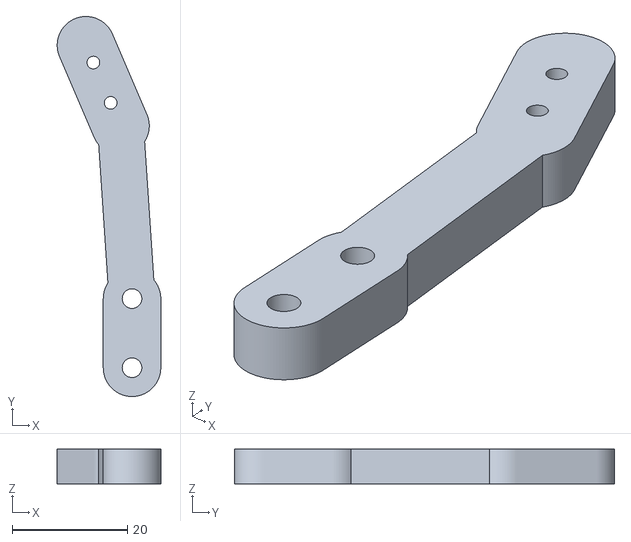
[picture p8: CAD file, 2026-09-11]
cad/college_v1/development_stl/claw/V1_Claw_Finger_Right.stl
18.0 x 66.0 x 6.00

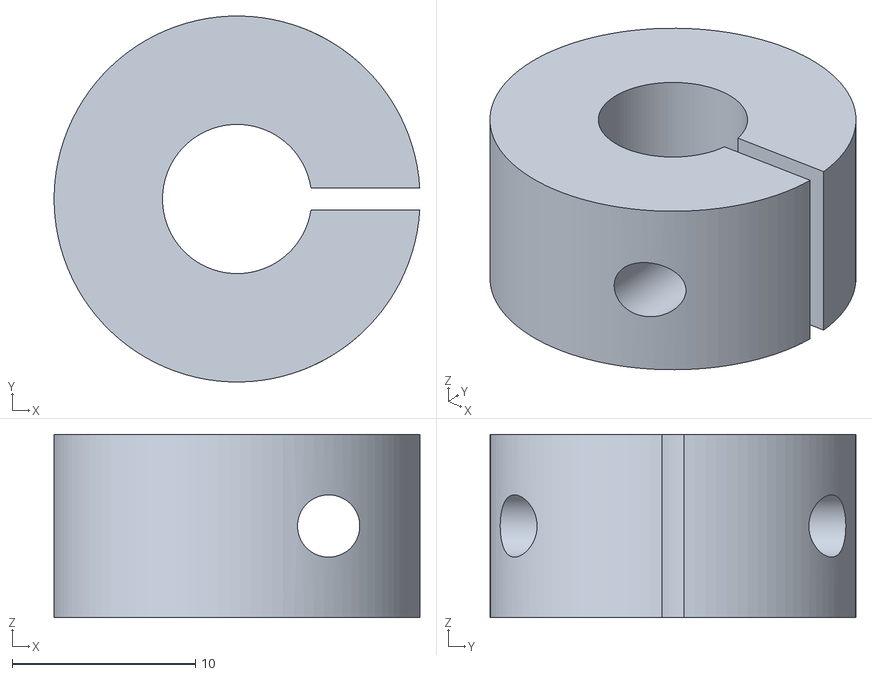
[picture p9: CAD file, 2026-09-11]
cad/college_v1/development_stl/frame_drive/V1_Collar8.stl
20.0 x 20.0 x 10.0

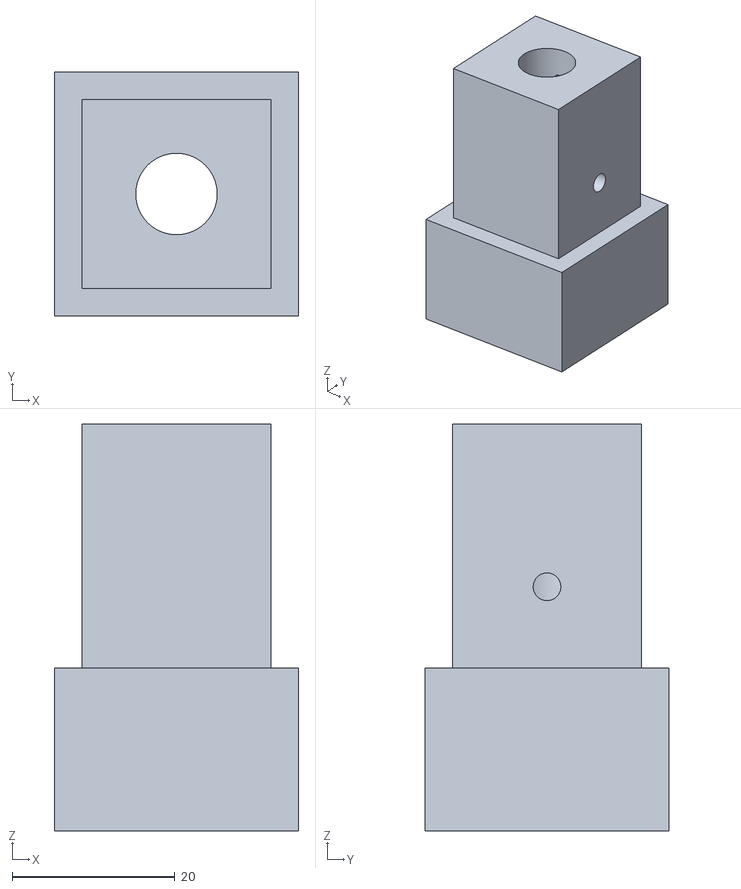
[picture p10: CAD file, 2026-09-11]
cad/college_v1/development_stl/telescope/Telescope_Joint_Male_Fit_Coupon.stl
30.0 x 30.0 x 50.0

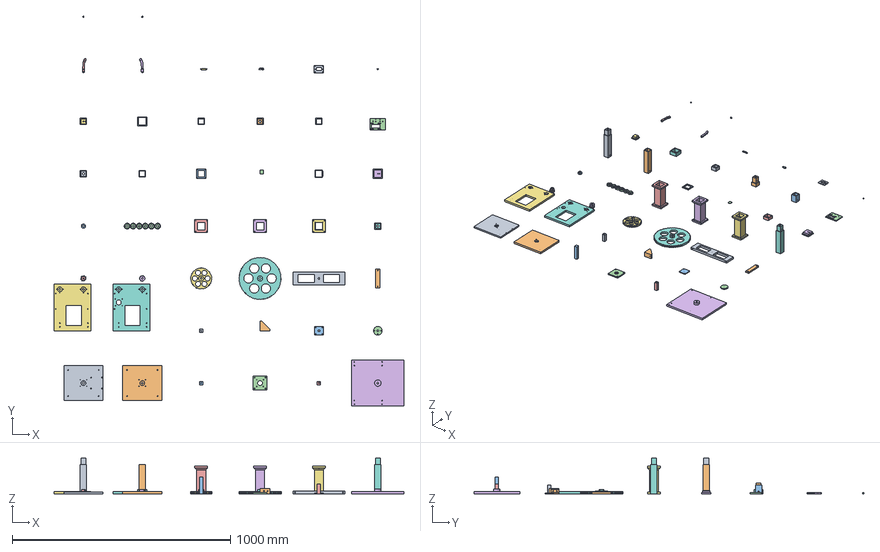
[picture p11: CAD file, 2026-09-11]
cad/college_v1/V1_Print_Development.FCStd
1605.0 x 1788.5 x 163.3 mm
V1_Base x1
V1_YawUpperDeck x1
V1_DeckSpacer76 x4
V1_YawMotorPlate x1
V1_MotorSpacer45 x4
V1_Turret x1
V1_YokeCheek x2
V1_OutboardGearPlate x1
V1_GearPlateSpacer40 x4
V1_YokeFoot x4
V1_BearingCap608 x2
V1_CheekBearingCap608 x4
V1_Pinion20_5mm x2
V1_Pinion20_8mm x1
V1_Gear80_8mm x2
V1_Gear160_8mm x1
V1_SaddleRail x2
V1_SaddleCrossbar x4
V1_Collar8 x6
V1_608FitCoupon x1
Telescope_Outer_1 x1
Telescope_Outer_2 x1
Telescope_Outer_3 x1
Telescope_Inner_1 x1
Telescope_Inner_2 x1
Telescope_Inner_3 x1
Telescope_Front_Guide_Cap x1
Telescope_Front_Guide_Pad x4
Telescope_Rear_Guide_Ring x1
Telescope_Rear_Tether_Cap x1
Telescope_Inner_Rear_Cap x1
Telescope_Outer_Fit_Coupon x1
Telescope_Inner_Fit_Coupon x1
Telescope_Joint_Male_Fit_Coupon x1
Telescope_Joint_Female_Fit_Coupon x1
V1_Claw_Palm x1
V1_Claw_Finger_Left x1
V1_Claw_Finger_Right x1
V1_Claw_Pushrod x2
V1_Claw_Crank_Adapter x1
V1_Claw_Servo_Carrier x1
V1_Claw_Spacer_1mm x5
V1_Claw_Spacer_2mm x1
V1_Claw_Spacer_6mm x1

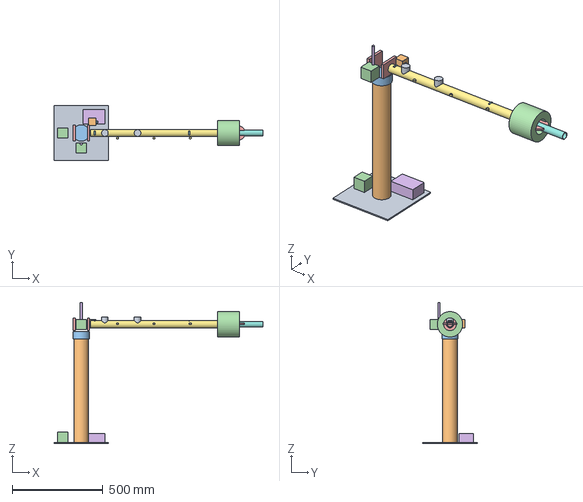
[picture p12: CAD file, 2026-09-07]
cad/step/VariableReachArm.step
1150.0 x 300.0 x 776.0 mm

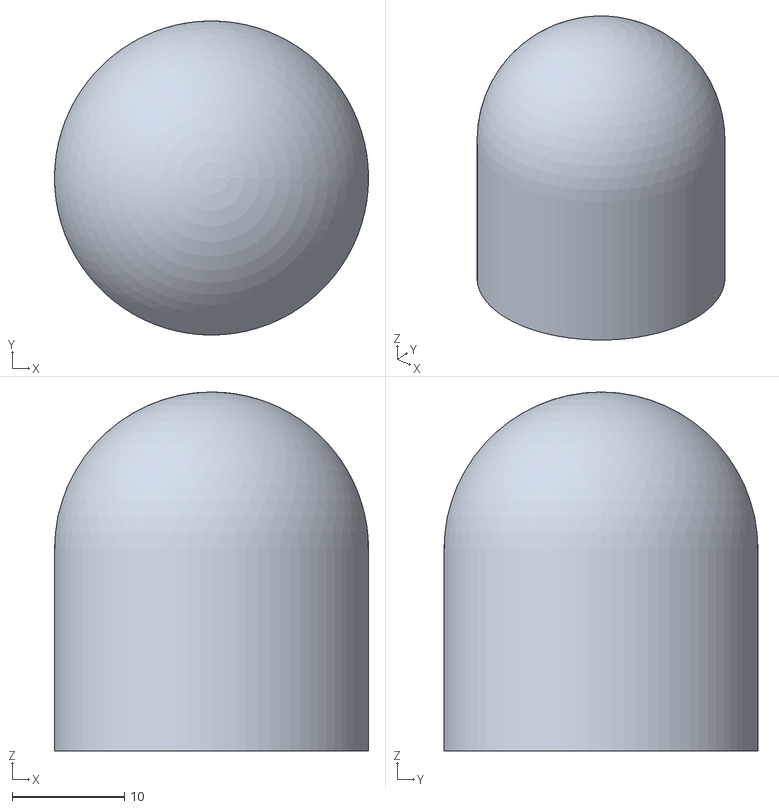
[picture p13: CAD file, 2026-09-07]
cad/stl/CatcherTipPad.stl
28.0 x 28.0 x 32.0

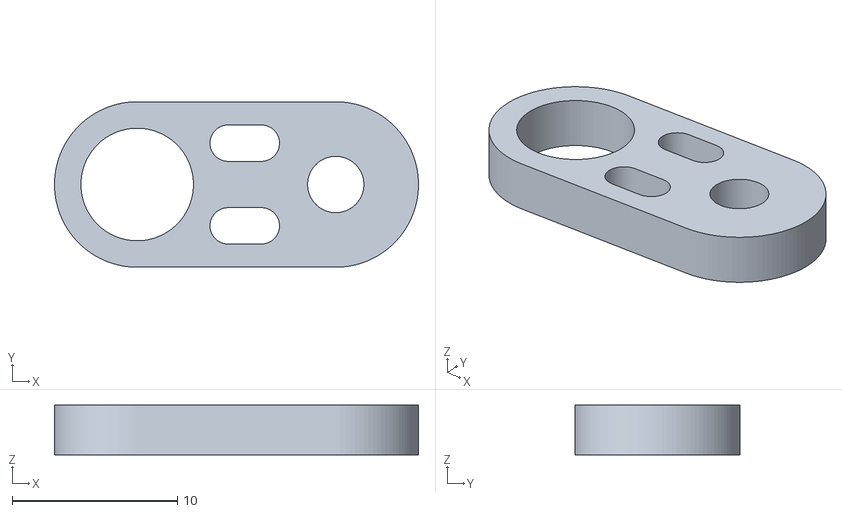
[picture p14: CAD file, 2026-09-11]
cad/college_v1/development_stl/claw/V1_Claw_Crank_Adapter.stl
22.0 x 10.0 x 3.00

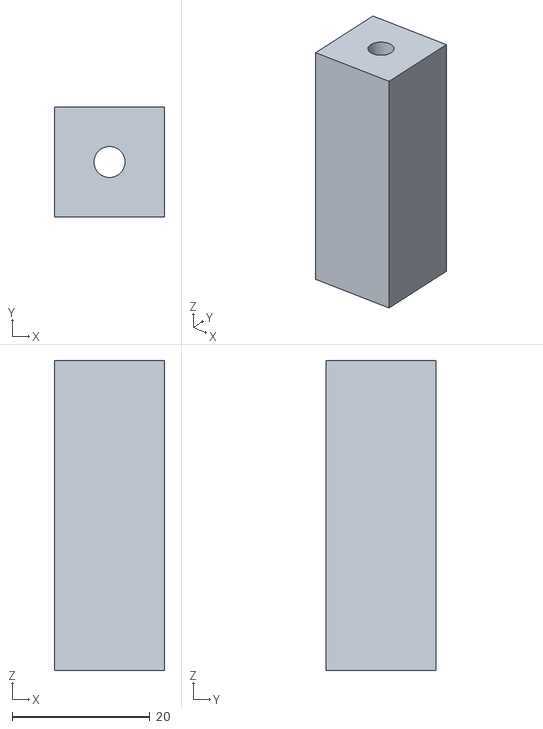
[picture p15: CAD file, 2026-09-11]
cad/college_v1/development_stl/frame_drive/V1_MotorSpacer45.stl
16.0 x 16.0 x 45.0

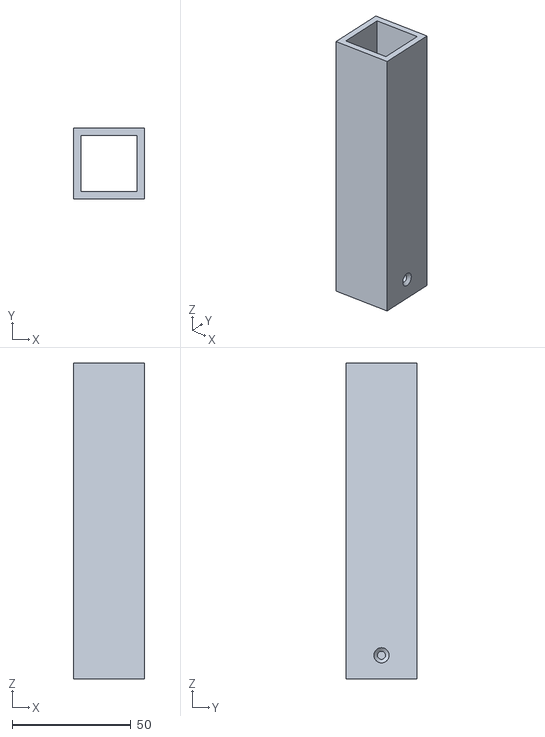
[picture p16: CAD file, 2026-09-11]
cad/college_v1/development_stl/telescope/Telescope_Inner_3.stl
30.0 x 30.0 x 133.3

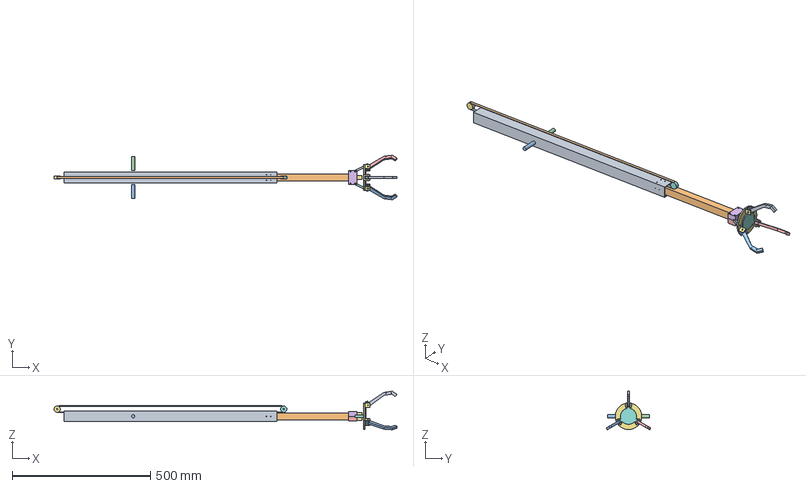
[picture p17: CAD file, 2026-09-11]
cad/review_b/Telescope_250mm.FCStd
1241.4 x 161.8 x 140.1 mm
OuterTube
InnerTube
FrontSidePad_0
FrontFacePad_0_0
FrontFacePad_0_20
FrontSidePad_2
FrontFacePad_2_0
FrontFacePad_2_20
RearSidePad_0
RearFacePad_0_0
RearFacePad_0_20
RearSidePad_2
RearFacePad_2_0
RearFacePad_2_20
DrivePulleyPitchEnvelope
IdlerPulleyPitchEnvelope
BeltInsideEnvelope
BeltReturnEnvelope
Trunnion_0
Trunnion_2
CatcherClamp_bottom
CatcherClamp_top
GripperPalm
PalmContactPad
Claw_1
ClawPin_1
Claw_2
ClawPin_2
Claw_3
ClawPin_3
GripperServoEnvelope
CatcherStrut_0
CatcherStrut_2

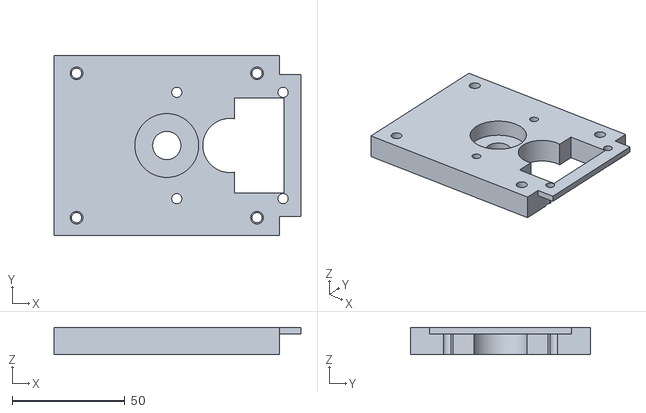
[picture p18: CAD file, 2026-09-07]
cad/stl/PitchCheek_L.stl
109.5 x 80.0 x 12.0

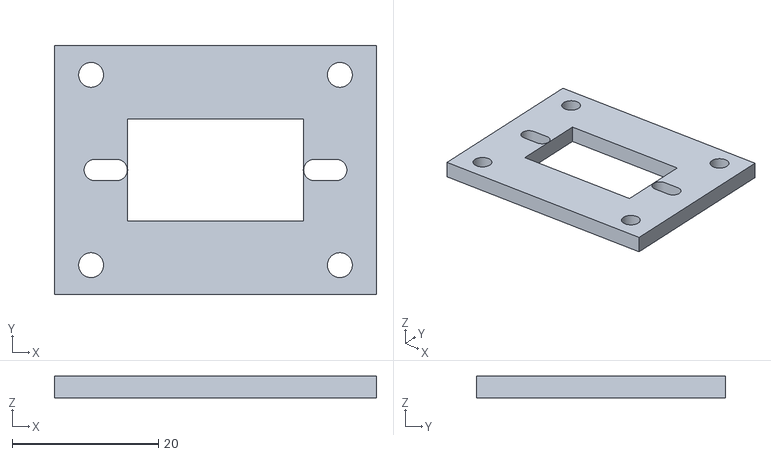
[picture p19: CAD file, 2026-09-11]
cad/college_v1/development_stl/claw/V1_Claw_Servo_Carrier.stl
44.0 x 34.0 x 3.00

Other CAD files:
cad/college_v1/development_stl/frame_drive/V1_608FitCoupon.stl
cad/college_v1/development_stl/telescope/Telescope_Front_Guide_Cap.stl
cad/review_b/Telescope_500mm_ClawsClosed.FCStd
cad/college_v1/development_stl/claw/V1_Claw_Finger_Left.stl
cad/college_v1/development_stl/claw/V1_Claw_Palm.stl
cad/college_v1/development_stl/claw/V1_Claw_Pushrod.stl
cad/college_v1/development_stl/claw/V1_Claw_Spacer_1mm.stl
cad/college_v1/development_stl/claw/V1_Claw_Spacer_2mm.stl
cad/college_v1/development_stl/claw/V1_Claw_Spacer_6mm.stl
cad/college_v1/development_stl/frame_drive/V1_Base.stl
cad/college_v1/development_stl/frame_drive/V1_BearingCap608.stl
cad/college_v1/development_stl/frame_drive/V1_CheekBearingCap608.stl
cad/college_v1/development_stl/frame_drive/V1_DeckSpacer76.stl
cad/college_v1/development_stl/frame_drive/V1_Gear160_8mm.stl
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

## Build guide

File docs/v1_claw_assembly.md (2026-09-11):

# Compact V1 two-finger claw: print and fit instructions

This is a real two-finger rigid grabber with one servo crank and two pinned rods. No net, springs or tendons. It is designed for restrained slow handling of a soft object up to 20 g. These are print-ready shapes, with the servo carrier and horn adapter explicitly **fit-test parts** until the actual servo is measured. It is not released for catching thrown objects.

## Print settings and inventory

All shapes are millimetres, flat on XY at Z=0. Use PETG, 0.20 mm layers, five perimeters, five top/bottom layers and 30% gyroid. A 0.4 mm nozzle is assumed. No supports are needed in the exported orientation. Inspect slicer preview and print a hole coupon first.

- Palm: one, 70 x 54 x 5 mm. Four M3 mounting holes at X=+/-10, Y=0 and 10 mm. Finger pivots at X=+/-22, Y=0 mm.
- Left finger and right finger: one each, 6 mm thick. Rear linkage pin 12 mm behind pivot; tip centre 44 mm ahead and 8 mm inboard. Two 2.2 mm holes in each finger retain bought foam pads with thread/ties. Do not buy a TPU spool just for these pads.
- Pushrod: two, 23.4094 mm hole-centre distance, 3 mm thick, 7 mm width.
- Crank adapter: one, 12 mm output pin radius, 3 mm thick. It bolts to a purchased servo horn; no printed spline.
- Servo carrier: one, 44 x 34 x 3 mm. Body window 24 x 14 mm. M2.5 flange slots cover 27-33 mm screw-centre spacing.
- Spacers: five 1 mm, one 2 mm, one 6 mm. Measured metal washers can replace them.

Every individual part fits even a Prusa MINI-sized bed. The exact Prusa model and material shrinkage still need checking. Ream printed 3.4 mm pivot holes only enough for the actual M3 smooth shank to rotate freely. Do not allow visible pivot wobble.

## Actual servo and horn fit gate

TowerPro lists the MG90S body as 22.8 x 12.2 x 28.5 mm and also lists width 12.4 mm in its configuration table. The carrier allows both nominal widths. Primary source checked 2026-09-08: https://towerpro.com.tw/product/mg90s-3/

That page does not establish a universal horn-hole pattern or a shaft-to-flange height for the user's unidentified servo and market variants. Print the carrier and adapter first. Dry-fit the actual hardware before printing the rest of the claw.

Use the original servo horn and its output screw. Bolt the printed adapter to that horn through **two M2 screws and nuts**, using its two 2.2 mm wide radial slots at Y=+/-2.5 and X=5.5-7.5 mm relative to shaft centre. A suitable disc/cross horn may require two drilled holes. Check there is enough horn material around both holes. If the supplied horn cannot accept this pattern, measure and revise the adapter or buy a compatible disc horn. Do not use only centre-screw friction to transmit torque.

Carrier centre is nominal X=-10, Y=-22 mm below the palm. Carrier M3 holes are at local X=+/-17, Y=+/-13. The palm slots allow +/-5 mm X adjustment. Set the actual servo output axis at **X=-12, Y=-20 mm**. The actual shaft Y position must be checked; if the body's available adjustment cannot achieve it, revise the carrier rather than forcing assembly.

The modeled crank occupies Z=10-13 mm above the palm bottom. Measure the real horn/shaft height. Use equal measured carrier spacers if necessary; if the modeled height cannot be reached with rigid support, revise the mount. The arm nose must clear the servo below the rear palm and must not fill the carrier aperture.

## Mechanical assembly

Use metal M3 bolts, washers and locknuts. A smooth shank should run through each moving hole. Do not tighten a nut against a moving printed link. Select screw lengths after measuring the full stack, with about two threads beyond the nut; keep protruding ends away from foam and fingers.

1. Mount palm through the four 20 x 10 mm pattern holes (rows at Y=0 and 10).
2. At each finger pivot, install a 1 mm spacer above the 5 mm palm, then the 6 mm finger. Finger bottom/top are Z=6/12 mm. Add washer and locknut and confirm free motion. M3 x 20 is a candidate pivot screw length, subject to actual washer/nut dimensions.
3. Electrically centre the servo before installing its horn, initially with rods disconnected. The modeled neutral shaft centre is (-12,-20); crank common pin is (0,-20); finger rear pins are (-22,-12) and (22,-12).
4. Left rear finger pin: 2 mm spacer above finger, then rod at Z=14-17 mm, washer and locknut. Right rear pin: 6 mm spacer, then rod at Z=18-21 mm, washer and locknut. M3 x 16 left and M3 x 20 right are candidate lengths; verify the actual stacks.
5. Common crank pin: crank top Z=13, 1 mm spacer, left rod, 1 mm spacer, right rod, washer and locknut. Both rods must rotate independently. An M3 x 16 or longer screw may be needed; measure before ordering packs.
6. With power disconnected, sweep every pose by hand and check screw heads, nuts and the underside of the fingers against the palm. Install foam pads and set the powered grip endpoint before any stall or hard jam.

CAD angles are not servo pulse widths. Do not send a generic 0-180 degree command. Begin with a narrow pulse sweep around a measured neutral and expand only after proving clearance. Limit the modeled crank to +/-25 degrees.

## Kinematics and checks

The common pin follows C=(-12+12*cos(a), -20+12*sin(a)). Each finger rear pin is P=(s*22+12*sin(t), -12*cos(t)), with side s=-1 or +1. The code solves the actual pinned-link equation distance(P,C)=sqrt(22^2+8^2), rather than moving disconnected links visually.

At crank -25 degrees, finger angles are +7.283 and -20.750 degrees. At neutral both are zero. At +25 degrees they are -11.148 and +0.483 degrees. Motion is asymmetric; it is a simple foam-object grabber, not a precision parallel gripper. Usable opening depends on pad thickness and object shape.

All nine unique printed shapes are valid single solids. Assembled printed-part overlap and rod closure checks are executed headlessly. They exclude purchased servo, horn and fasteners and do not prove continuous clearance, strength or durability. No universal powered-ready claim should be made until the servo fit gate passes.

## Acceptance before demonstrating

First fit the carrier and horn. Confirm the servo cannot shift under a gentle hand load. Hand-sweep the complete linkage with actual bolts, nuts, pads and the arm attached. All pins must rotate freely with no visible wobble. Route and restrain the servo wire outside the moving links.

Then use a current-limited supply for slow empty cycles, followed by a soft object of at most 20 g. Record voltage, current, heat and loosening. Stall torque is not continuous gripping torque. Keep hands outside pinch points. Likely failure modes are PETG creep, hole ovalization, horn-adapter loosening and pad detachment. Stop at a crack, loose interface, overheating or stalled servo.

This subsystem is specific to the compact printed V1. It does not release or replace the full-size fair-version claw without a separate design decision.

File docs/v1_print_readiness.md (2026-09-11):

# Compact V1 print-readiness pass — 2026-09-08

## Release decision

Nine small fit-check files may be printed for unpowered dimensional testing. The entire compact robot is NOT ready to manufacture. A closed manifold mesh and successful slicing do not establish a connected, complete machine. The 44 exported CAD parts include five coupon geometries; the development quantity of 80 includes those coupons. Missing drive/wrist/restraint interfaces are desk-design work still to be completed.

## Corrections implemented

- Claw palm mounting holes intersected servo-carrier adjustment slots → fasteners could not seat independently → moved the four interface holes to X=±10, Y=0/10 mm → narrower mounting pattern needs matching wrist design → code, notes and STLs updated.
- Shoulder bearing pockets broke through the 200 mm plate top → insufficient bearing containment → raised cheek/outboard plates to 215 mm → extra material and printer-envelope constraint → regenerated valid solids. This is not a bearing-load qualification.
- Large gear lightening holes disconnected the hub → visually plausible but unusable mesh → reduced hole radii → some mass added → single-solid validation passes.
- Gear teeth lacked nominal printing backlash → binding likely → relieved tooth thickness by 0.12 mm on each gear, nominal pair clearance 0.24 mm → more backlash than ideal gears → 14 sampled mesh positions clear; actual print fit still needed.
- Motor gear retention initially required a bolt crossing the shaft → impractical motor-shaft modification → tangential split-hub clamp clear of shaft plus D-bore torque transfer → printed clamp creep remains possible → revised hubs and mesh exports. Final axial retention not qualified.
- Round saddle sockets relied on friction for pitch torque → potential slip → blind D-shaped sockets → generic shaft requires measured filing → implemented, while full stubshaft retention remains outstanding.
- Rear guide assumed 0.30 mm tape while candidate BOM names 0.13 mm → wrong guide clearance → use 34.14 mm ring OD plus two 0.13 mm tapes = 34.40 mm against 34.80 mm bore → adhesive/tape thickness needs measurement → CAD and docs synchronized.
- Front guide M3x12 adjusters were too short for the flange stack → inadequate adjustment reach → changed candidate to M3x16 → verify engagement and tip contact on real parts → documentation corrected.
- Telescope fit checks previously required long tube segments → wasted material before joint verification → added cropped male/female coupons using the exact production spigot, countersinks and nut paths → 41.9 g approximately for the pair → exported and sliced.
- Heavy bearing gauge was simplified into six joined annular cups → lower filament cost and additional 22.3/22.4 mm options → pocket cuts must follow web union → final modeled bearing clearance check caught and removed a web obstruction. Notched end identifies 21.9 mm pocket.

## Verification

FreeCAD 1.1 validates all 44 shapes as single connected solids; all closed STL meshes pass PrusaSlicer 2.9.6 manifold and slicing checks. Slicing records include SHA256 of every verified STL; packaging rejects stale records. Generic check uses 0.4 mm nozzle, 0.20 mm layer, six perimeters, five top/bottom layers and 25% gyroid. Actual printer and filament profile selection remains with the operator; no G-code is delivered.

Claw clearance: 51 sampled positions from -25 to +25 degrees, nominal carrier included, rod closure checked. Purchased hardware excluded. Gear pairs: 14 rigid pose samples, excluding material/thermal deformation. Bearing gauge: actual 22 mm OD / 8 mm ID / 7 mm bearing envelope seats without modeled interference in pockets ≥22 mm; the 21.9 mm option intentionally has interference.

## Do before bulk printing

1. Close telescope belt drive, anchors, motor/idler supports, physical stops and sensor mounts.
2. Build the wrist interface using actual servo/horn dimensions; verify carrier output-axis position and shaft height.
3. Finish complete shoulder/yaw shaft lengths, bearing spacer/cap stack, gravity restraint, motor access and cable routing.
4. Check full compact assembly poses with hardware envelopes and intended clearances. The inventory-grid FCStd is NOT an assembled robot.
5. Reconcile the named candidate purchasing BOM: previous yaw/pitch belts and spring/tendon claw no longer match this development CAD; additional long M4 bolts, countersunk M3 joint screws, M2/M2.5 servo hardware and adhesive are needed. The old two-spool allowance is insufficient: current sliced inventory is about 2.70 kg before missing design parts/rework. Three spools is a minimum inventory allowance, not a new fixed total project quote.

## Physical fit information required

Actual Prusa model/nozzle, PETG profile, 608 bearing fit, PTFE tape including adhesive thickness, and actual servo/horn measurements. These are separate from the outstanding desk-design tasks above. Do not use missing measurements as justification to call unfinished interfaces complete.

Original/fair-version CAD remains preserved. No repository commit, hardware command, firmware flashing or powered test was performed in this pass.

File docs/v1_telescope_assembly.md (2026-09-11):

# Compact V1 printed telescope: assembly and limits

This is a new compact **low-speed fit prototype**, not the existing full-size fair assembly. All dimensions are millimetres. Mesh validity and printer-envelope checks do not establish structural strength or a powered-motion release.

## Geometry

- Outer boom: 380 long, 42 square, 34.8 square bore; three 126.667-long segments. Assembly span X=-180 to200.
- Outer joint flange:60 square,8 thick, four3.4 clearance holes at +/-25 in both cross-sectional directions. Upper flange underside uses a45-degree ramp; each part stands upright on its lower flange.
- Inner boom:400 long,30 square,23.6 square bore; three133.333-long segments. First two have30-long internal23.2-square bonded spigots, so the tallest print is163.333. Assembly span X=-130+extension to270+extension.
- Normal commanded stroke:200. Nominal remaining tube overlap at maximum stroke:130. This must be enforced by controller and a separately qualified travel restraint. Guide contact alone does not stop at200.
- Front pad shoulder lies at X180..182; pads occupy X182..198 and the removable guide cap X200..204. Inner tube-to-cap clearance is0.4 per face, before print error and deflection. Nominal rear guide ring centre X=-122+extension; guide spacing is312 mm retracted and112 mm extended.
- Local model Z becomes assembly X with a+90 degree rotation aroundY. All exported models rest on Z=0. Nothing requires a build envelope greater than60x60x163.333.

## Print first: fit coupons

Print the outer and inner coupons in the same PETG, layer height, extrusion calibration and orientation intended for the long parts. Use0.20 layers, six perimeters,0.4 nozzle baseline. Do not scale meshes to correct fits; change the relevant dimensions and regenerate. Check that the30 mm inner coupon slides squarely in the outer without rotation-sensitive binding. Actual Prusa model, nozzle and filament profile remain to be selected in PrusaSlicer.

Next print one front pad, the rear guide ring and the short male and female joint coupons as fit checks. The outer-to-inner free gap is intentionally taken up by guides. Measure the PTFE tape including adhesive: nominal0.13 mm. Rear ring outside34.14 plus tape on both faces makes34.4, leaving0.4 total nominal clearance in34.8 bore. If your tape differs, adjust ring dimensions. Do not substitute an arbitrary tape thickness.

## Inner joints

Use four M3x12 DIN965/ISO7046 90-degree countersunk screws, four M3 DIN934 nuts and plastic-compatible epoxy for the two joints. On each spigot insert two nuts through the10 mm axial access bore into the radial pockets before mating. The two screw axes are90 degrees apart, at10 and22 from the joint. Test access and engagement on a coupon before bonding. The screw head must be flush or below the30 mm outside surface. A protruding screw or glue ridge can jam the front guide. Do not countersink so deeply that the shell cracks.

The spigot has0.2 mm adhesive allowance per face. Degrease using a filament-compatible process, roughen only the bonding surfaces, align on a flat reference, and clamp straight through cure. PETG adhesive strength is formulation-dependent: perform a sacrificial joint bending test; the geometry is not a bonded-joint strength certification. The joint remains a first-likely failure location because upright prints load interlayer bonds in boom bending. Move slowly and retain the arm while testing.

## Outer joints and guides

Use eight M3x20 bolts, sixteen M3 washers and eight M3 nuts across the two flange joints. Assemble around a straight temporary mandrel or use the completed straight inner tube as an alignment reference without glue contact. Slightly loose3.4 holes allow alignment; tighten evenly. Do not use bolt force to straighten warped prints.

Bond the rear guide ring over the rear16 mm of the inner tube and apply PTFE on its outer four faces. The rear cap is mounted after the ring. Keep the seam and tape edges flush. The rear cap plate sits X=-135+extension to-130+extension; its plug projects into the bore. Outer rear cap plate sits X=-185..-180. Caps currently use bonded plug retention; they are not certified impact-stop mounts.

Insert the inner tube from the front before attaching its claw. Place the four front guide pads between the printed shoulder and removable cap, PTFE against the inner tube. Orient each pad's16 mm dimension along the boom. Four M3x16 screws through the outer flange adjust the pads; M3 nuts in the external hex pockets provide threads. Fit M3 jam nuts externally if screw length and access permit. The pad dimple receives the screw tip. The front cap uses four M3x8 screws in2.5 mm printed pilot holes. Drill the pilots to measured suitable size; start with a coupon and do not overtorque plastic threads.

Adjust until the unloaded telescope traverses the entire200 mm stroke by hand with no catching or excessive shake. Recheck under a modest transverse hand load. A guide screw is an adjustment, not a structural bolt: crushing a pad increases friction and creep.

## Travel restraint, drive and outstanding interfaces

The rear caps provide two4 mm cord bores. A low-stretch2 mm stop cord between the caps can be arranged to become taut at200 mm extension (nominal anchor separation250 mm). Measure the actual installed anchor locations and knot take-up: do not cut a250 mm cord and assume it produces250 mm working length. A separate external redundant restraint is required during powered testing because cap glue and knots are unqualified. Keep cord slack contained behind the moving rear guide; prove it cannot enter the guide or drive. This is not an energy absorber or a precision homing switch. Normal motion must decelerate before the cord is taut.

External belt motor/idler mounts, belt attachment, limit switches and a robust adjustable hard stop are NOT yet implemented in the compact assembly. They remain design work, not merely physical validation. No powered-release claim is made for this standalone subsystem. Do not run open-loop extension until the complete assembly supplies those items and a loss-of-power restraint.

## Validation performed

FreeCAD1.1 shape checks:15 unique parts, all valid, each one connected solid, all at bedZ=0 and within180 mm in every dimension. Upper flange ramps avoid long horizontal support shelves. Horizontal radial holes may require drilling; nut pockets and spigot fit require a physical coupon. Full slicer preview must verify first-layer contact, perimeters and bridges using the actual printer profile. No G-code or universal printer profile is implied.

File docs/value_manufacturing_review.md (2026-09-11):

# Value-focused fabrication decisions — Rev B

The objective is low total cost for useful catching performance, not maximum printed
mass. Print the complex shapes, replaceable interfaces and fixtures. Buy inexpensive
standard parts wherever stiffness, heat, wear or safe load retention dominates.
The complete machine remains a design study; the current fit STL manifest is not a
release of every part described below.

## BOM changes implemented in this pass

Problem → the bill omitted M2 guide hardware and a separate servo supply and called
the rigid claws TPU. Why it matters → missing purchased packs and a noisy/overloaded
logic rail invalidate both the cash budget and electronics integration. Implemented
→ both current BOMs now include the 24 M2x8 screws, 24 nuts and 24 thin washers within
a larger hardware allowance, a separate $8 unquoted servo-regulator allowance, rigid
fingers in structural filament, and TPU for pads. Reduction-kit descriptions exclude
the six separately counted 6001 bearings and use the common filament line for any
qualified printed large pulley. Tradeoff → honest cash totals rise $16.74 including
allowances; nothing about these entries qualifies a part for ordering.

Full machine: $1,131.30 parts, $135.76 shipping/tax allowance, $190.06 redesign
reserve, **$1,457.12 planning cash**. Alternative restrained telescope/claw rig:
$386.10 parts, $46.33 shipping/tax allowance, $64.86 reserve, **$497.29 cash**.
Shipping/tax is rounded to cents, then reserve is rounded on that subtotal.
These are alternative
baskets, not additive. Most prices remain explicitly unquoted. The existing PC,
printer, rigid bench and ordinary tools are excluded; confirm printer/bench access.
No camera, PSU or filament is counted as owned. The ESP32 is $0 purchase cost but
needs a qualified firmware port. The unknown owned servo receives no speculative
credit. Miscellaneous EE parts are credited only when identified and suitable.

The raised-shoulder CAD alternative is not selected or included. Exact motors,
ratios, bus voltage, brake, guard dimensions and camera synchronization can change
this budget materially. In particular the currently cited 48 V motor curve does
not qualify the candidate 24 V power system. The $480.55 rig is not a three-axis
catching robot and has only $19.45 of headroom under $500.

## Where printing gives good value

The detailed process and hardware requirements are in `cad/drawings/print_guide.md`.
Default to one PETG spool for cold housings, claw fit parts and jigs, plus TPU only
for compliant parts. Avoid purchasing PETG, ASA, nylon and CF nylon simultaneously.
Use ASA or qualified nylon only when measured temperature, creep or impact results
justify their printing difficulty and cost. Manufacturer printability/material
properties support this starting choice; they do not establish structural allowables
for our geometry ([Prusa material guide](https://help.prusa3d.com/category/material-guide_220)).

Print claw fingers, palm, servo cradle/straps, sensor brackets, guards against finger
access, wire clips, bearing caps, drill templates and fit coupons. Conditional
hybrids include tube clamps, bearing carriers and large reduction pulley webs with
metal hubs. These avoid custom machining and exploit geometry that flat stock cannot
easily provide. Use bought acetal shoes for the actual small sliding contact surfaces;
generic filament friction/wear is not qualified by appearance. Engineered printed
bearing polymers can work, but require specific material/testing rather than generic
PETG substitution ([igus bearing materials](https://www.igus.com/3d-printing/3d-printed-bearings)).

Use drilled aluminum stock for long tubes, hot motor/tension plates, thin stiff
cheeks/rails and critical stop load paths. Use real steel shafts/pins, bearings,
belts, metal motor pinions, springs and brake parts. Their standard mass-produced
versions provide better value than spending iteration time trying to reproduce
precision or fatigue properties in FDM. A large printed base/column consumes a spool
and print time while creating compliant joints; triangulated stock is the better
starting architecture. Containment uses suitable polycarbonate/frame, not an
untested thin printed cover.

## Concrete value choices and savings boundaries

1. **Preserve aluminum tubes; defer carbon fiber and premium motors.** The current
   model already spends far more than $500. A $50 upgrade for 5% improvement is not
   accepted by default. It must remove a measured limiting failure, save other parts,
   or materially improve repeatable catch success. There is no measured performance
   basis to purchase carbon fiber now. Aluminum offcuts also provide test coupons.
2. **Reuse the ESP32 and possibly the servo.** The board already saves $35 versus the
   earlier full-machine MCU allowance ($8 versus the old rig MCU allowance). Servo
   credit cannot equal the whole $20/$16 claw-hardware line because springs, tendons
   and pins remain required. Identify its model and bench-test travel/current first.
3. **Print large pulley webs only after tooth/runout qualification.** Bought metal
   hubs and small pinions remain. There is no booked cash saving yet because current
   transmission kit prices are allowances, and a smooth CAD envelope is not a
   printable timing tooth profile. Obtain like-for-like metal and hybrid quotes.
4. **Use stock drops and common hole sizes.** The $70 frame allowance assumes basic
   cutting/drilling, no outsourced machining. Quote the final cut list locally;
   do not replace a needed metal load path with plastic merely to avoid one drill
   operation. Printed hole-position jigs are a useful low-cost aid, followed by
   measured coaxiality/alignment checks.
5. **Test a low-cost foam contact insert before buying an entire TPU spool solely
   for one palm.** A mechanically trapped foam pad could reduce the full $24 (rig
   $22) spool cash requirement, minus foam and retention cost. This is a conditional
   experiment, not a booked saving: bounce, durability and capture retention need
   comparison and CAD retention details must be updated. Rigid fingers remain.
6. **Stage purchases, reuse the same telescope.** The restrained rig avoids buying
   angular motors and cameras before friction/claw viability is measured. This lowers
   immediate spend, not final full-machine cost. Do not buy all rig parts and then
   rebuy duplicated full-machine parts; credit actual reusable purchases line by line.
7. **Prefer targeted stiffness fixes over blanket infill or material upgrades.**
   Reorient a part, shorten a lever, increase bearing separation or add a rib before
   choosing expensive filament. Preserve mass at the tip. Weigh complete assemblies;
   sliced plastic cost is not complete hardware mass or full-spool cash cost.

Never count removal of brake, independent cutoff, fuses, required feedback or guards
as a value improvement. Instead reduce the qualified operating envelope or build a
restrained subsystem until the complete safety function is affordable. No shopping
list currently demonstrates the full requested high-speed capability below $500.

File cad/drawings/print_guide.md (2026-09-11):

# Rev B print and stock fabrication guide

Print as much of the useful geometry as practical, while preserving the metal load
paths and bought wear/precision components. This supersedes earlier generic printed
carriers that are absent from the current CAD. The CAD uses square aluminum tubes
and three rigid hinged claws with compliant contact pads, **no net**.

Only the four STL files listed in `cad/review_b/print_manifest.json` are currently
exported fit prototypes. Other parts below describe fabrication intent and require
current CAD exports, exact hardware grip lengths and checks before fabrication.
Do not use legacy `cad/stl/` as a released production pack. None of these process
settings certifies powered operation or high-speed impact strength.

## Common process and acceptance

Starting settings assume a calibrated 0.4 mm nozzle and 0.2 mm layers. Perimeters
provide the load path; infill does not replace ribs, adequate wall thickness or
proper orientation. Use broad washers and captive nuts/through-bolts for primary
loads. Heat-set inserts are appropriate for covers and light adjusters, not the
only tensile retention of a shoulder. Avoid forcing printed press fits. Measure
stock, print a bore coupon, and drill/ream the final fit rather than prescribing a
universal printer compensation. Record filament, conditioning, temperature and
slicer settings. Inspect layer bonding and proof-test actual oriented coupons.

Use PETG for inexpensive cold fit parts and guards. ASA is an alternative where
measured heat/creep demands justify an enclosed print process. Tough dry nylon is
an optional later impact material, not a required third spool. PLA+ suits jigs and
unloaded mockups; avoid it in hot/preloaded mechanisms. CF-filled filament has no
automatic strength credit and is not a substitute for laminated carbon-fiber tube.

## Should be 3D printed

**Rigid claw fingers (three ClawFitPrototype copies):** PETG first, qualified tough
nylon if impact tests demand it. Lay the broad finger face flat so root bending
is in the layer plane. Six perimeters, 35–45% infill, local solid pivot/horn region,
no supports on hinge surfaces. Current finger thickness is 8 mm with nominal
3.3 mm pivot bore for a measured 3 mm smooth steel pin; preserve at least 3 mm
ligament around the pivot and rounded root transitions. Retain pads through M2
holes. Do not print pins or run pivots on screw threads. Failure modes: root/horn
crack, bore wear, tendon abrasion and pad pullout. Test a whole mounted finger,
not only a generic tensile coupon.

**Palm (GripperPalmFitPrototype):** PETG for fit, ASA/qualified nylon for later
service. Plate flat; six perimeters, 35–45% infill. Current ring is 46 mm outer/
30 mm inner radius with a 4 mm plate. The 12 mm clevis gap receives an 8 mm finger
and nominal 2 mm thrust spacers each side. That nominal stack has no endplay: fit
real shims to obtain approximately 0.1–0.2 mm free axial movement without wobble.
Use smooth metal pins with positive retention and M3 broad washers at pad/strut
attachments. Do not tighten a locknut until a pivot binds. Upright clevis ears are
vulnerable to layer peel; strengthen/reorient into a split assembly if proof tests
show peeling. Failures: ear delamination, pin escape and strut-mount cracks.

**Compliant palm/finger pads (PalmPadFitPrototype plus fitted finger pads):** TPU
95A starting material, broad face flat; 3–4 perimeters, 15–25% infill. Mechanically
retain with broad washers and rounded edges; no adhesive-only retention. Current
palm pad is 4 mm thick, mounted with three M3 fixings and 1 mm standoff. It cannot
be credited with 25 mm stopping travel. Test force/displacement, bottoming, rebound
and tear; a trapped foam insert is a separate economical experiment. Do not print
the entire rigid finger in TPU merely because it touches a ball.

**Servo cradle and straps:** PETG cold fit prototype, ASA if measured servo heating
requires it. Cradle floor down, six perimeters and 30–40% infill; straps broad face
down with at least four perimeters. Current allowance body is 24 × 13 × 29 mm;
cradle floor is 3 mm, nominal towers 4 × 4 mm, straps 2 mm. Use M2 through-bolts/
washers for straps and common M4 clamp bolts through two 5 mm metal spacers at the
mount foot. Do not trust towers as printed threads. Fit the actual servo before
printing a service version; horn motion/wiring must clear the whole claw sweep.
Failures: strap/tower splitting, long arm flexure, preload creep and wire pinching.
This cradle supports a packaging envelope; it does not qualify the unknown servo.

**Cable clips, switch/sensor mounts, low-energy finger-access covers, electronics
tray and drill jigs:** PETG, broad mounting face down, 3–4 perimeters, 15–25% infill,
2 mm minimum cover wall and rounded strain-relief edges. M3 inserts/through-bolts,
service loops and tie points on both sides of connectors. Keep heat-producing
resistors/drivers off plastic or provide a rated metal spreader/standoff. Failure
modes: loose sensor datum, cracked tabs, chafed wires and heat distortion. A printed
cover is not validated projectile containment or an electrical fire enclosure.

## Can be printed if designed and qualified correctly

**GuideFitCoupon:** PETG, channel axis vertical as exported, 5–6 perimeters, 30–40%
infill. Compare measured stock face spacing, corner radius, straightness and guide
access. It is a coupon only. Current actual shoes are solid acetal with recessed
M2 hardware, not a PETG carrier plus an unmodeled liner. Do not assemble the coupon
as a sliding structural guide or force it onto stock.

**Split tube/catcher clamps and pitch saddle bodies:** PETG for unpowered fit; ASA
or tested nylon for a qualified hybrid. Print split face down, 6–8 perimeters,
40–50% infill, ribs at bolt ears with rounded roots. Maintain the current 22 mm
catcher-clamp length, approximately 3.5 mm wall, four M4 holes and deliberate split
closure clearance; fit against measured 25.4 mm tube. Pitch saddles fit 38.1 mm
outer stock and must transfer load to metal shoes/rails/stubs with through-bolts.
Use broad washers/locknuts, metal compression stops as needed, no insert-only
primary load path. Failures: clamp slip, split-ear peel, tube crushing and creep.
Nominal CAD clearance does not establish clamping friction or bolt preload.

**Pitch/yaw bearing carriers and caps:** ASA or tested nylon, split/bore axis chosen
so radial bearing load remains in continuous perimeter paths; mounting flange flat
is a coupon starting orientation. Eight perimeters, 40% infill, at least 5 mm
support ribs where geometry permits. Current pitch/jackshaft bearings are 6001 class
12 × 28 × 8 mm; yaw bearings 6204 class 20 × 47 × 14 mm. Preserve actual race
shoulders and metal load spreading. Never clamp inner and outer races together or
hammer bearings into an undersized print. Use metal through-bolts, sleeves and
positive axial caps. Failures: outer-race creep, ovalization, cap pullout and
coaxiality loss. Hot/preloaded carriers may require stock-metal replacement.

**Large reduction pulley webs and flanges:** optional PETG for low-load trials,
ASA/qualified nylon for later service. Shaft axis vertical, 6–8 perimeters,
40–50% infill, locally solid tooth ring and hub bolt region with a ribbed web.
Use a purchased metal clamp hub and through-bolted pattern. A current smooth pitch
envelope is not an exportable timing pulley: generate the actual compatible tooth
profile and check belt seating, runout, tooth loading and thermal creep first.
Do not put a setscrew directly into printed plastic. Failure modes: tooth shear,
ratcheting, eccentricity and hub/web splitting. Do not make a printed pulley the
only power-loss gravity restraint. Savings are not booked until quotes and proof
loads demonstrate the hybrid is worthwhile.

## Should probably be stock metal or purchased polymer

**Small sliding guide shoes:** cut/drill acetal stock; print drill and fit fixtures.
There are six front and six rear shoes, nominal 30 mm axial length; top/bottom
strips are 6 mm wide at ±8 mm centers, giving a 10 mm corridor around a 9 mm belt.
Radial shoe thickness is nominal 4.6625 mm for the present tube pair; actual tube
corner radii and tolerance decide final shimming. Twenty-four recessed M2x8 socket
screws, 24 nuts and 24 thin washers retain them. Keep heads at least 0.5 mm below
the sliding face, verify screws do not protrude and preserve the staggered service
holes. Hand-cycle the full stroke under transverse load before powered testing.
Failures: screw scraping, pad migration, wear, overpreload binding and nut loss.
Cheap generic printed shoes are not automatically economical after repeated jams.

**Motor/tension plates, yoke cheeks, saddle rails/shoes, long column/braces and
base:** use drilled aluminum plate/angle/tube with printed hole jigs. These parts
carry belt preload, heat and long-lever bending; thin stock usually beats thick
FDM in stiffness per mass and print time. Print only temporary motor-envelope
mockups in PETG (six perimeters, 30% infill, flange flat, through-bolts); do not
power-load them on that basis. Current metal CAD needs its actual cut/drill list,
coaxiality, wrench access and material grade checked. Failures include bracket
flexure, slot slip, tube crushing and anchor pullout. A plywood bench fixture is
a possible stationary rig support, not a drop-in rotating-yoke substitution.

**Containment panels:** suitable purchased polycarbonate and anchored frame; printed
edging/clips are acceptable after panel-retention checks. Keep this separate from
cosmetic belt guards. Panel thickness and retention depend on credible projectiles;
there is no blanket safety credit for transparent sheet.

## Should definitely not be consumer-FDM printed

- Outer 38.1 mm and inner 25.4 mm structural telescoping tubes: purchased aluminum,
  nominal 1.5875 mm walls, 770/805 mm cut lengths. Measure actual stock dimensions.
- Steel pitch/yaw/jackshafts, smooth claw pins, shaft collars and loaded metal hubs.
- Rolling bearings, small drive pinions and loaded idler bearing running surfaces.
- Timing belts, load-bearing tendons, torsion/extension springs and spring retainers
  where a printed failure could eject the spring; use metal retention and guards.
- Primary telescope stop straps/contacts and pitch brake/independent fall restraint.
  Print replaceable bumpers around a metal secondary stop only after energy tests.
- Structural screws, nuts, washers, electrical contactors, fuses and bus dump resistor.

These decisions apply to the user's consumer polymer printer. They are not claims
about industrial metal printing. Keeping inexpensive bought hardware is normally
better value than reproducing precision, heat resistance and fatigue properties.

## Before spending on full assemblies

Check the four fit prints and measured tubes first. Weigh complete tip hardware,
servo, springs/tendons and wiring against the model's 170 g distal allowance.
Select actual purchased interfaces before final-fit exports. Hand-assemble and
cycle through every stroke/jaw angle, inspect tool access, record slip/friction,
and proof-test the intended load paths. Powered trials additionally require the
release gates in `docs/bringup.md` and `docs/safety.md`; print settings alone do not
release a subsystem. `docs/value_manufacturing_review.md` records cash totals and
conditional savings without pretending a restrained rig is the full robot.

## Added drive hardware — current baseline

- Rear plug and stop collars: can be printed after fit and load qualification; PETG for fit, qualified tough nylon for cyclic parts. Print collars with tube axis normal to the bed, 6 perimeters and 40% infill, and use through-bolts with metal washers. Collar slip, lug layer separation and creep are principal failures. Measure the actual tube before choosing clearance.
- Front idler bracket: conditional print, 6 perimeters and 40% infill; orient its bridge/load path in the layer plane and split the carrier if necessary. Use metal bearing caps, shaft and spacers. Check bridge bending and bearing-seat creep before powered operation.
- Claw fingers/palm: print as specified above; new spring slots and 2 mm stop pins require fit coupons before a full set. Buy springs and metal pivots; do not print them.
- TPU stop pads: print solid in their small keyed section; do not assume the full 3 mm thickness is usable stopping stroke. Treat pads as replaceable consumables.
- Belt clamp cap, 5 mm stop pins/retainers, shafts, bearings and small toothed pulleys: purchased/cut metal. These inexpensive parts carry concentrated loads and are poor places to save a few dollars by printing.

These additions are CAD prototypes, not released print files. See the telescope and claw design documents for assembly order and unresolved dimensions.
> Compact college V1 override: the user accepts lower performance and maximum
> practical printing. For that separate compact design, bearing caps, belt-clamp
> caps, pulley bodies, base, shoulder and both boom shells are planned as printed
> parts. See `engineering/college_v1_print_manifest.json` and
> `docs/college_v1_named_bom.md`. Metal-only guidance for the larger high-speed
> Rev B must not be applied to V1 by default. Compact printable CAD is not released.

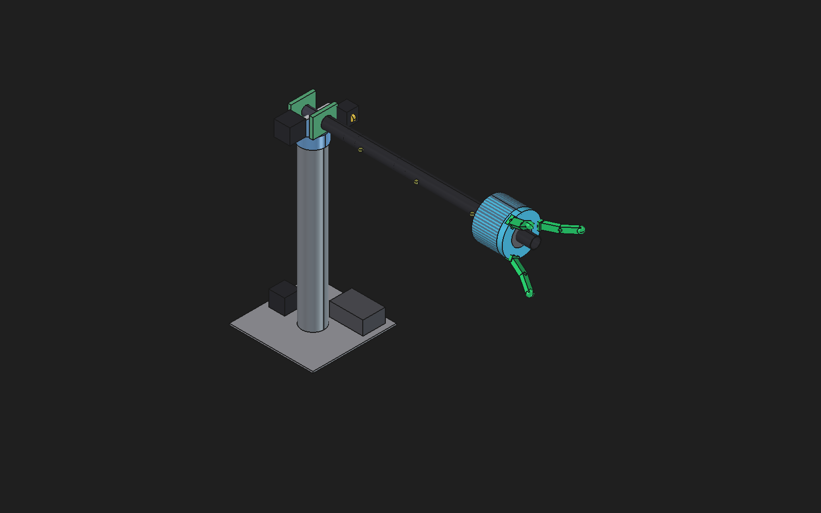
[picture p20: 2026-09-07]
cad/drawings/assembly_iso.png

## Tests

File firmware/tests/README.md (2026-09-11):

# Embedded verification

From repository root:

```sh
g++ -std=c++17 -Wall -Wextra -Werror -I firmware/include firmware/tests/test_native.cpp firmware/src/command_receiver.cpp firmware/src/protocol.cpp firmware/src/safety.cpp firmware/src/control_loop.cpp firmware/src/motors.cpp -o vra_native_tests
./vra_native_tests
VRA_NATIVE_TEST_BINARY=./vra_native_tests python -m unittest discover -s firmware/tests -v
python -m platformio run -d firmware
```

On Windows, set VRA_NATIVE_TEST_BINARY to the absolute .exe path using a process
environment variable. Zig's C++ frontend can replace g++ if necessary. Tests cover
the standard CRC check vector, 32-bit angular range, invalid values, unsupported
claw/home/trajectory commands, sequence wrap/replay, corrupt/dropped/truncated frame
recovery, qualification lock, missing feedback and anti-windup. The optional
cross-language test compares exact C++ command bytes with Python and decodes C++
telemetry; it must run before a protocol change is accepted.

The production CommandReceiver shared with main.cpp is exercised in actual byte
receive/dispatch order: boot, enable, clear, unsupported HOME/TRAJ/claw, invalid
range/flags/CRC, old-sequence disable, reset-link, duplicate/stale/new sequence,
wraparound, truncated/dropped-frame recovery and reboot. Read-only safety snapshots
verify invalid or replayed traffic does not refresh host-arrival health. No test
replaces the safety implementation or adds an enable bypass.

Controller reset clears and invalidates targets and measured state. Tests verify
that a new measurement alone cannot revive the old target. The future measured-pose
handoff still requires timestamped feedback and an explicit, qualified arm transition;
this release supplies neither.

No tests invoke a serial port or flash a board. No test bypasses FLT_UNQUALIFIED.
Host/native tests cannot exercise real driver shutdown, encoder loss timing, current
trips, homing, independent watchdog or brake behavior because those adapters do not
exist. Follow docs/safety.md before any powered axis testing.

A Teensy compile checks target syntax/linking, not measured 1 kHz timing, electrical
safety or real motion performance.

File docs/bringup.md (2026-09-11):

# Bring-up — current revision and future gates

**Only unpowered mechanical checks, offline simulation and logic-only firmware
diagnostics are supported now.** Homing and real motor control are absent.
FLT_UNQUALIFIED cannot be cleared by the host. Do not remove it to try old jog
instructions. No hardware was flashed during this review.

## Work possible now

1. Print Rev B fit coupons. Measure tube dimensions, wall, corner radii and
   straightness. Record part and material revisions.
2. With motor power physically disconnected and the mechanism restrained, check
   hand travel, guide friction, accessible hardware and belt/claw clearances.
   Complete undeveloped interfaces before treating the CAD study as a mechanism.
   Minimum overlap is 240 mm; minimum guide spacing is 190 mm.
3. Verify smooth steel claw pivot grip, thrust spacers and retention. Start an
   isolated contained claw fixture with hand insertion and low-energy soft-ball
   tests. Measure mass, closure, stopping travel and retention; no net.
4. Run engineering, host and protocol regressions and python -m simulation.run_demo.
   Board diagnostics require inspected wiring and a physically disconnected motor
   bus. Verify missing-feedback sentinels, CRC/sequence handling, rejected commands
   and the persistent lock using docs/embedded_protocol.md.

## Gate before powered single-axis trials

These are required future tasks, not implemented instructions:

- Select the exact motor/driver and loaded torque curve, voltage/current settings
  and command/feedback interface. Implement timestamped feedback, bounded homing,
  following-error detection and deterministic bounded motion.
- Complete rated DC cutoff/manual reset, independent watchdog/enable, fuses,
  regenerative clamp and guarded travel. Verify the power circuit separately.
- Complete belt/pad retention, both hard-stop load paths and harness strain relief.
  Restrain the first telescope horizontally; omit gravity-loaded pitch motion.
- Prove startup, command loss, feedback/limit faults and reset cannot enable motion.
  Test independent stopping first on an unloaded drive, then at low energy in the
  restrained rig; record stop distance, residual force and voltage/current waves.
  motors_disable_all() is a stub, not proof of a physical cutoff.

Begin below proposed bench caps with reduced current and bounded profiles only
after these gates. Caps are future experiment ceilings, not authorization to power
this revision. Expand after measured acceptance and fault injection.

## Later integration

Finish base anchorage, yaw/pitch bearings/hubs and independent pitch drop restraint
before adding rotation. Test axes separately then together. Calibrate joint/camera
frames, total latency and prediction error; qualify claw closure/retention.
A physical containment barrier and empty active workspace are required for
high-speed or autonomous trials. Throwing follows deliberate release qualification.
See docs/testing.md and docs/safety.md.

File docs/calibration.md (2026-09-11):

# Calibration contract

Firmware has no qualified driver/encoder/homing implementation. Do not follow the
historical instruction to drive toward a named pin. Qualify the restrained homing
procedure and independent stop first; see bringup.md.

Use the documented base frame: +Z up, zero yaw along +X, zero pitch horizontal.
Measure pitch-axis origin and actual claw entry plane. Extension zero is a measured
soft reference, not hard-stop contact. Store SI offsets, signs, uncertainty, actual
hardware identity and config revision together.

With motor energy isolated, manually verify encoder sign and scale over known
motion. A motor encoder cannot detect all transmission slip or establish tip
accuracy. Later measure repeated low-speed switch approaches only on a qualified
restrained rig. Record switch and soft-limit positions separately with stopping
clearance before the physical stop.

No camera is owned or qualified. Calibrate chosen cameras at their actual resolution,
focus and crop, including distortion, stereo pose and rectification. Validate on
held-out surveyed3D points across the volume. Store serial numbers and image size
with calibration. Measure the camera-to-base transform and document its direction.
Test detection under lighting changes, occlusion and blur; reject ambiguous pairs.

Use exposure capture timestamps, not host arrival timestamps. Independently measure
frame skew, timestamp uncertainty and capture-to-command latency. Nominal FPS is
not latency. Nonzero stereo timing uncertainty requires an explicit speed bound;
see planning_deadlines.md. Calibration and association errors need separate bounds
beyond the implemented timing/pixel gate.

Measure actual capture volume, claw angle, closure/release delay and pad compliance
on the isolated fixture. CAD mouth position is not a measured grasp region. Repeat
checks after changes to tubes, guides, belts, cameras or claws; retain old files.

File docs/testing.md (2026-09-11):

# Subsystem testing — development, not powered release

The current firmware refuses powered operation. Do not bypass that lock. Complete
qualified driver, feedback, homing, independent stop, brake and power interfaces
before any restrained powered test. See bringup.md and safety.md.

## Records

Record CAD/config/firmware revision, actual parts, payload, reach, supply voltage,
ambient temperature and instrument calibration. Save raw capture-time samples
under data/experiments/. Report sample count, RMS, maximum and 95th percentile;
separate measured results from targets and include measurement uncertainty.

## Unpowered mechanics

1. Measure tube dimensions, corner radii and straightness; print the guide coupon
   first. Verify screw access and retention before installing long tubes.
2. With motor/belt disconnected, measure breakaway and running force in both
   directions at 0/125/250/375/500mm stroke, unloaded and with proposed tip load.
   Run20 slow traversals. Jamming, pad migration, screw contact or tube damage
   fails. Compare measured friction with sizing assumptions.
3. Load the tip in both bending directions at three reaches. Subtract fixture
   compliance; report force/displacement slope and residual displacement. Compare
   against the model and positioning error budget. The old25mm allowance is not
   a stiffness qualification. Measure torsional compliance and reversing backlash.
4. Check bolt witness marks, access, assembly order and cables over full travel.
   Verify stop contact before guide/belt disengagement. CAD checks alone do not
   qualify tolerances, stopping capacity or fatigue.

## Logic/electronics without motor energy

Run documented host, engineering and production-dispatch tests. On the selected
MCU, measure loop jitter under worst communications load. Inject stale/malformed
commands, replay, invalid encoders, unexpected limits and watchdog timeout; verify
latched faults and deliberate rearming. Test independent energy removal using a
dummy load. A telemetry flag or motors_disable_all stub is not electrical proof.

## Future restrained powered tests

After release gates close, start with independent current/speed/travel limits,
no projectile, and no person in the swept volume. Prove homing direction first.

- Extension: log position, velocity and current for20 repeated moves. Report
  endpoint/midpoint repeatability. Document filtering when deriving acceleration.
- Pitch/yaw separately at three reaches: RMS/peak error, overshoot, repeatability,
  settling within a stated band, and slip/lost-step checks. Compare variable-inertia
  predictions to measurements before scheduling gains or increasing speed.
- Thermal/power: monitor temperatures through representative duty until stable.
  Measure simultaneous acceleration current and braking bus voltage with suitable
  instruments; a DMM cannot capture short regenerative peaks. Compare actual
  ratings with margin, not assumed efficiency alone.
- Vibration: measure dominant frequency and decay versus extension after a small
  move/impulse; use the results to constrain trajectory bandwidth.

## Vision and planner

Validate fixed surveyed points, then independently measured moving trajectories.
Report position/prediction error by horizon, depth, speed, lighting and occlusion.
Measure capture, transport, detection, planning and command latency separately,
including tail latency and stereo clock uncertainty. Replay tracks through reach,
partial-extension, unreachable, stale-data, late-dispatch, saturation and collision
cases before connecting an executor. Never compress a late trajectory to catch up.

## Claw and eventual contained catches

Test the claw alone with a soft known-mass ball behind containment. Measure closure
and release time, retention, bounce-out, pad force/displacement, wear and power-loss
behavior. Compare compliance, velocity matching and bounded radial retreat only
after each is independently qualified. Acceleration is not force without a model.

Later report all attempts and rejected opportunities, binned by incoming speed,
distance and extension, with sample counts. Report both attempted-catch success
and overall opportunity success. Increase energy only after a repeatable lower
stage. Throwing requires separate release-timing and containment validation.

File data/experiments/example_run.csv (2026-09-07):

timestamp | yaw_pos | yaw_target | yaw_vel | pitch_pos | pitch_target | pitch_vel | ext_pos | ext_target | ext_vel | current_yaw | current_pitch | current_ext | ball_x | ball_y | ball_z | ball_x_meas | ball_y_meas | ball_z_meas | intercept_x | intercept_y | intercept_z | catch_result | fault_bits
0.00 | 0 | 0 | 0 | 20 | 20 | 0 | 700 | 700 | 0 | 100 | 120 | 80 |  |  |  |  |  |  |  |  | -1 | 0
0.10 | 2 | 5 | 20 | 22 | 25 | 30 | 700 | 700 | 0 | 200 | 300 | 90 | 0.9 | 0.05 | 1.1 | 0.9 | 0.05 | 1.1 |  |  |  |  | 0
0.20 | 5 | 8 | 30 | 28 | 35 | 40 | 720 | 800 | 400 | 250 | 400 | 200 | 0.88 | 0.05 | 1.05 | 0.88 | 0.05 | 1.05 | 0.85 | 0.05 | 0.95 |  | 0
0.40 | 8 | 8 | 0 | 35 | 35 | 0 | 950 | 980 | 200 | 180 | 350 | 220 | 0.85 | 0.05 | 0.90 | 0.85 | 0.05 | 0.90 | 0.85 | 0.05 | 0.90 | 1 | 0

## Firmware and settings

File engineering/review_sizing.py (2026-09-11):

"""Reproducible Rev B engineering screens; standard library, SI throughout.

This predicts requirements. It does not certify an actuator, printed part or machine.
Geometry comes from design_parameters.json. See calculations.md for derivations,
model limits, sources, acceptance gates and the difference between target and bench.
"""
from __future__ import annotations
import csv
import json
import math
from pathlib import Path

ROOT = Path(__file__).resolve().parent
G = 9.80665


def parameters():
    return json.loads((ROOT / 'design_parameters.json').read_text(encoding='utf-8'))


def square_section(side, wall):
    if not all(math.isfinite(x) for x in (side, wall)) or not 0 < 2*wall < side:
        raise ValueError('invalid square tube section')
    bore = side - 2*wall
    # Bredt closed thin-wall torsion constant, NOT polar bending moment.
    return side**2-bore**2, (side**4-bore**4)/12, (side-wall)**3*wall


def bodies(extension, p=None, loaded=True):
    p = p or parameters()
    g, m, mat = p['geometry'], p['mass_allowances'], p['material']
    if not math.isfinite(extension) or not 0 <= extension <= g['extension_stroke_m']:
        raise ValueError('extension outside design stroke')
    a, b = g['outer_start_m'], g['outer_end_m']
    outer_mass = square_section(g['outer_side_m'],g['outer_wall_m'])[0]*(b-a)*mat['density_kg_m3']
    il = g['inner_length_m']
    inner_mass = square_section(g['inner_side_m'],g['inner_wall_m'])[0]*il*mat['density_kg_m3']
    # name, kg, axial COM m, distributed rod length m, translates with extension.
    return [
        ('outer',outer_mass,(a+b)/2,b-a,False),
        ('inner',inner_mass,g['inner_retracted_start_m']+extension+il/2,il,True),
        ('catcher',m['catcher_and_tip_wiring_kg'],g['normal_reach_m']+extension-g['catcher_com_behind_mouth_m'],0,True),
        ('ball',m['ball_kg'] if loaded else 0,g['normal_reach_m']+extension-g['catcher_com_behind_mouth_m'],0,True),
        ('rear_guide',m['rear_carriage_kg'],g['rear_guide_retracted_center_m']+extension,0,True),
        ('front_guide',m['fixed_front_guide_kg'],g['front_guide_center_m'],0,False),
        ('minimum_stop',m['minimum_stop_kg'],-.2335,0,False),
        ('maximum_stop',m['maximum_stop_kg'],.287,0,False),
        ('front_idler',m['front_idler_kg'],.525,0,False),
        ('extension_drive',m['extension_motor_and_bracket_kg'],m['extension_motor_com_x_m'],0,False),
        ('trunnions',m['pitch_clamps_and_trunnions_kg'],0,math.sqrt(12)*m['pitch_clamps_radius_m'],False),
    ]


def inertial_terms(extension, p=None, loaded=True):
    bs = bodies(extension,p,loaded)
    return {'I':sum(m*(r*r+length*length/12) for _,m,r,length,_ in bs),
            'I_prime':sum(2*m*r for _,m,r,_,moving in bs if moving),
            'first_moment':sum(m*r for _,m,r,_,_ in bs),
            'slider_mass':sum(m for _,m,_,_,moving in bs if moving),
            'total_mass':sum(m for _,m,_,_,_ in bs)}


def dynamics(extension, pitch, rates, accelerations, p=None, loaded=True):
    """Rigid-line boom spherical-coordinate inverse dynamics, no friction.

    rates and accelerations = (yaw, pitch, extension), pitch zero horizontal.
    Boom cross-section rotary inertias and motor gyroscopic terms are omitted:
    narrow beam screen only. Rotor J is estimated; procurement requires exact J.
    """
    p = p or parameters()
    t = inertial_terms(extension,p,loaded)
    d, m, g = p['drivetrain'],p['mass_allowances'],p['geometry']
    wy,wp,vs = rates
    ay,ap,ac = accelerations
    if not all(math.isfinite(v) for v in (pitch,*rates,*accelerations)):
        raise ValueError('nonfinite state')
    cp,sp = math.cos(pitch),math.sin(pitch)
    I,Ip = t['I'],t['I_prime']
    jp = d['motor_rotor_inertia_kg_m2_assumed']*d['pitch_ratio']**2
    jy = d['motor_rotor_inertia_kg_m2_assumed']*d['yaw_ratio']**2
    turret = m['yaw_carried_motor_bracket_kg']*m['yaw_carried_motor_bracket_radius_m']**2
    radius = g['extension_belt_pitch_m']*g['extension_pulley_teeth']/(2*math.pi)
    extension_reflected_mass = 5e-6/radius**2  # assumed NEMA17 J; not published data
    return dict(pitch_nm=(I+jp)*ap+Ip*vs*wp+I*wy*wy*sp*cp+G*t['first_moment']*cp,
                yaw_nm=(I*cp*cp+turret+jy)*ay+(Ip*vs*cp*cp-2*I*sp*cp*wp)*wy,
                extension_n=(t['slider_mass']+extension_reflected_mass)*ac-Ip/2*(wp*wp+wy*wy*cp*cp)+t['slider_mass']*G*sp,
                pitch_inertia_kgm2=I+jp,yaw_inertia_kgm2=I*cp*cp+turret+jy)


def guide_load(extension, transverse_tip_n=0.0, p=None, pitch=0.0,
               rates=(0.0,0.0,0.0), accelerations=(0.0,0.0,0.0),
               tip_force_yaw_n=0.0):
    """Exact distributed inertial guide reactions in both transverse planes.

    Each body has acceleration a(r)=k*r+c; integrate its force and moment,
    including local rod moment m*l²/12. Sign = guide force needed on slider.
    Tip forces add to that demand. Contact is assumed on opposing pad faces.
    Coulomb sliding model requires measured friction/preload and excludes binding.
    """
    p = p or parameters()
    g,d = p['geometry'],p['drivetrain']
    front,rear = g['front_guide_center_m'],g['rear_guide_retracted_center_m']+extension
    span = front-rear
    if span <= 0:
        raise ValueError('guide spacing must be positive')
    wy,wp,vs = rates
    ay,ap,_ = accelerations
    cp,sp = math.cos(pitch),math.sin(pitch)
    # Yaw centripetal acceleration projects POSITIVELY onto e_pitch.
    # e_pitch=(-sin(p)cos(y),-sin(p)sin(y),cos(p)); using a negative sign
    # understates pad loads while yawing with the boom raised.
    kp, cp_acc = ap+wy*wy*sp*cp,2*vs*wp+G*cp
    ky, cy_acc = cp*ay-2*sp*wp*wy,2*vs*cp*wy
    result=[]
    for k,c,tip in [(kp,cp_acc,transverse_tip_n),(ky,cy_acc,tip_force_yaw_n)]:
        force,moment = tip,tip*(g['normal_reach_m']+extension-rear)
        for _,mass,x,length,moving in bodies(extension,p):
            if moving:
                force += mass*(k*x+c)
                moment += mass*(k*(x*x+length*length/12-rear*x)+c*(x-rear))
        rf=moment/span
        result.append((rf,force-rf))
    front_vector=(result[0][0],result[1][0])
    rear_vector=(result[0][1],result[1][1])
    front_norm,rear_norm=math.hypot(*front_vector),math.hypot(*rear_vector)
    # Square shoes react on separate orthogonal faces: Coulomb normals add
    # component-wise. Using the vector resultant would understate by up to sqrt2.
    normal=sum(abs(component) for component in (*front_vector,*rear_vector))+d['guide_preload_total_n_assumed']
    return dict(span_m=span,front_n=front_norm,rear_n=rear_norm,
                front_pitch_yaw_n=front_vector,rear_pitch_yaw_n=rear_vector,
                friction_n=d['guide_friction_coefficient_assumed']*normal+d['extension_drag_n_assumed'],
                nominal_pad_pressure_pa=max(abs(component) for component in (*front_vector,*rear_vector))/(g['guide_length_m']*g['guide_pad_width_m']))


def guide_bound(extension, envelope, transverse_tip_n=0.0, p=None):
    """Triangle-inequality bound for independently bounded motion, any pitch.

    We integrate |r| and |r-rear| exactly on sign-separated polynomial intervals,
    so rear overhangs cannot cancel bounding loads.
    """
    p = p or parameters()
    g,d=p['geometry'],p['drivetrain']
    front,rear=g['front_guide_center_m'],g['rear_guide_retracted_center_m']+extension
    span=front-rear
    w,v=envelope['angular_speed_rad_s'],envelope['extension_speed_m_s']
    kp=envelope['pitch_accel_rad_s2']+w*w/2
    ky=envelope['yaw_accel_rad_s2']+2*w*w
    cp,cy=2*v*w+G,2*v*w
    total_p=total_y=moment_p=moment_y=0.0
    for _,mass,x,length,moving in bodies(extension,p):
        if not moving:
            continue
        if length:
            lo,hi=x-length/2,x+length/2
            points=sorted({lo,hi,*[v for v in (0.0,rear) if lo<v<hi]})
            ar=abr=product=0.0
            for left,right in zip(points,points[1:]):
                mid=(left+right)/2
                sr=1 if mid>=0 else -1
                sb=1 if mid>=rear else -1
                ar += sr*(right*right-left*left)/2
                abr += sb*((right-rear)**2-(left-rear)**2)/2
                product += sr*sb*((right**3-left**3)/3-rear*(right*right-left*left)/2)
            ar,abr,product=ar/length,abr/length,product/length
        else:
            ar,abr,product=abs(x),abs(x-rear),abs(x)*abs(x-rear)
        total_p += mass*(kp*ar+cp)
        total_y += mass*(ky*ar+cy)
        moment_p += mass*(kp*product+cp*abr)
        moment_y += mass*(ky*product+cy*abr)
    # Sum orthogonal flat-face reaction magnitudes; diagonal external load can
    # produce sqrt2 times its resultant in face-normal sum.
    rf=(moment_p+moment_y+math.sqrt(2)*transverse_tip_n*abs(g['normal_reach_m']+extension-rear))/span
    rr=total_p+total_y+math.sqrt(2)*transverse_tip_n+rf
    normal=rf+rr+d['guide_preload_total_n_assumed']
    return dict(span_m=span,front_n=rf,rear_n=rr,
                friction_n=d['guide_friction_coefficient_assumed']*normal+d['extension_drag_n_assumed'],
                nominal_pad_pressure_pa=max(rf,rr)/(g['guide_length_m']*g['guide_pad_width_m']))


def beam_screen(extension, tip_force_n, torque_nm=1.0, p=None):
    """Conservative piecewise beam-only compliance screen, NOT an upper bound
    on assembled deflection. Outer to moving rear guide, inner thereafter.
    Unbonded overlapping tubes are not treated as a composite section.
    Compliance of the last115mm claw mount is unknown; its replacement by tube
    EI in this screen cannot establish actual catcher rigidity.
    """
    p=p or parameters()
    g,mat=p['geometry'],p['material']
    L=g['normal_reach_m']+extension
    joint=max(0,g['rear_guide_retracted_center_m']+extension)
    _,io,jo=square_section(g['outer_side_m'],g['outer_wall_m'])
    _,ii,ji=square_section(g['inner_side_m'],g['inner_wall_m'])
    compliance=((L**3-(L-joint)**3)/io+(L-joint)**3/ii)/(3*mat['youngs_modulus_pa'])
    stress=max(tip_force_n*L*g['outer_side_m']/2/io,tip_force_n*(L-joint)*g['inner_side_m']/2/ii)
    clearance=g['guide_total_lateral_clearance_m']
    span=g['front_guide_center_m']-(g['rear_guide_retracted_center_m']+extension)
    return dict(tip_deflection_m=tip_force_n*compliance,compliance_m_n=compliance,
                max_bending_stress_pa=stress,yield_factor=mat['yield_strength_pa']/stress if stress else None,
                twist_rad=torque_nm*(joint/jo+(L-joint)/ji)/mat['shear_modulus_pa'],
                tip_lost_motion_from_guide_clearance_m=clearance*(1+(L-g['front_guide_center_m'])/span),
                limitation='tube-only elastic screen; excludes root/bearings/pad contacts/claw compliance, belt elasticity, local crushing and stress concentrations')


def catch_energy(ball_mass, relative_speed, stroke, peak_factor=2.0):
    if min(ball_mass,stroke) <= 0 or relative_speed < 0 or peak_factor < 1:
        raise ValueError('invalid impact inputs')
    energy=0.5*ball_mass*relative_speed**2
    return dict(relative_speed_m_s=relative_speed,assumed_stroke_m=stroke,energy_j=energy,
                average_force_n=energy/stroke,assumed_peak_force_n=peak_factor*energy/stroke,
                nominal_constant_decel_time_s=2*stroke/relative_speed if relative_speed else 0,
                peak_status='assumed shape factor; physical measurement mandatory')


def radial_catch_match(ball_radial_m_s, hand_radial_m_s, commanded_retraction_m_s):
    """Positive radial = outward. Retraction is a negative hand velocity.
    This compares instantaneous relative radial speeds only, not a full controller.
    """
    if commanded_retraction_m_s > 0:
        raise ValueError('retraction velocity must be nonpositive')
    before=ball_radial_m_s-hand_radial_m_s
    after=ball_radial_m_s-commanded_retraction_m_s
    return dict(relative_radial_before_m_s=before,relative_radial_after_m_s=after,
                reduces_radial_impact=abs(after)<abs(before))


def shaft_belt_screen(output_torque_nm, external_radial_n, pitch_ratio=8.0):
    """Preliminary two-stage HTD5 20:40 then20:80, shaft reactions.
    Final trunnion layout changes require recalculation. 12mm steel shaft;
    final80T pulley radius63.66mm, unsupported length20mm. T0=100N/strand.
    If slack tension goes negative this preload is insufficient.
    """
    pitch=0.005
    radius=80*pitch/(2*math.pi)
    difference=abs(output_torque_nm)/radius
    preload=100.0
    tight,slack=preload+difference/2,preload-difference/2
    belt_radial=2*preload if slack>=0 else difference
    diameter=0.012
    bending=(belt_radial+external_radial_n/2)*0.020
    bending_stress=32*bending/(math.pi*diameter**3)
    shear=16*abs(output_torque_nm)/(math.pi*diameter**3)
    von_mises=math.sqrt(bending_stress**2+3*shear**2)
    return dict(output_pulley_pitch_diameter_m=2*radius,belt_tension_difference_n=difference,
                assumed_preload_each_strand_n=preload,tight_tension_n=tight,slack_tension_n=slack,
                preload_sufficient=slack>0,motor_pulley_direct_load_n=2*preload,
                driven_bearing_radial_n=belt_radial+external_radial_n/2,
                shaft_bending_moment_nm=bending,shaft_von_mises_pa=von_mises,
                shaft_yield_factor_assuming_250mpa=250e6/von_mises if von_mises else None,
                shaft_local_stress_factor_allowance=2.0,
                shaft_yield_factor_with_local_allowance=250e6/(2*von_mises) if von_mises else None,
                release='requires purchased belt rating, true bearing layout, steel grade, hub grip and fatigue review')


def motor_demand_curve(output_torque_nm, output_speed, ratio, efficiency, margin=1.5):
    if min(ratio,efficiency,margin) <= 0:
        raise ValueError('invalid drive factors')
    return dict(ratio=ratio,motor_rpm=abs(output_speed)*ratio*60/(2*math.pi),
                load_torque_nm=abs(output_torque_nm)/(ratio*efficiency),
                minimum_available_running_torque_nm=margin*abs(output_torque_nm)/(ratio*efficiency),
                margin_required=margin,available_running_torque_nm=None,qualified=False,
                reason='exact voltage/current/driver torque-speed curve not yet verified; holding torque is not capacity')


def claw_closure_screen():
    """Illustrative unmeasured finger mechanism. No spring/servo selected by this.
    All numbers are test parameters; low-friction fixed torque approximation.
    """
    finger_mass,length,pad_mass=0.018,0.11,0.004
    inertia=finger_mass*length**2/3+pad_mass*length**2
    travel,spring_torque,friction=0.45,0.015,0.005
    ideal_time=math.sqrt(2*inertia*travel/(spring_torque-friction))
    servo_radius,finger_horn=0.010,0.012
    # Three tendons, each opening against spring plus friction.
    servo_required=3*(spring_torque+friction)*servo_radius/finger_horn
    return dict(status='illustrative assumptions; measure every parameter',finger_inertia_kg_m2=inertia,
                finger_close_travel_rad=travel,spring_torque_each_nm=spring_torque,
                assumed_friction_torque_each_nm=friction,ideal_contactless_closure_time_s=ideal_time,
                ball_transit_60mm_at4m_s_s=0.060/4,
                servo_open_torque_nm_with_2x_margin=2*servo_required,
                warning='contact-triggered spring closure is much slower than ball transit in this example; compliant capture geometry and predictive preposition required')


def extension_hardstop_screen(effective_mass, speed, pulley_radius, stroke=0.003):
    """Current 5mm smooth steel pins; conservatively one pin takes first contact.
    Three millimetres is the modeled TPU axial pad thickness, not proven usable
    energy-absorbing stroke. A 2x mean pulse is illustrative, not a peak guarantee.
    """
    energy=0.5*effective_mass*speed**2
    force=2*energy/stroke+0.6/pulley_radius
    diameter=0.005
    overhang=0.004
    bending=32*force*overhang/(math.pi*diameter**3)
    shear=force/(math.pi*diameter**2/4)
    vm=math.sqrt(bending*bending+3*shear*shear)
    return dict(kinetic_energy_j=energy,assumed_usable_pad_stroke_m=stroke,
                average_force_n=energy/stroke,illustrative_design_force_n=force,
                single_pin_von_mises_pa=vm,pin_yield_factor_assumed250mpa=250e6/vm,
                maximum_unsupported_pin_length_m=overhang,
                status='Not released: actual steel grade, usable pad stroke, impact pulse, collar slip, printed lug strength and tube bearing require qualification; no normal hard-stop deceleration')


def envelope_row(extension,envelope,p):
    t=inertial_terms(extension,p)
    d,g=p['drivetrain'],p['geometry']
    w,v=envelope['angular_speed_rad_s'],envelope['extension_speed_m_s']
    ap,ay,ae=envelope['pitch_accel_rad_s2'],envelope['yaw_accel_rad_s2'],envelope['extension_accel_m_s2']
    jp=d['motor_rotor_inertia_kg_m2_assumed']*d['pitch_ratio']**2
    jy=d['motor_rotor_inertia_kg_m2_assumed']*d['yaw_ratio']**2
    turret=p['mass_allowances']['yaw_carried_motor_bracket_kg']*p['mass_allowances']['yaw_carried_motor_bracket_radius_m']**2
    pitch=(t['I']+jp)*ap+abs(t['I_prime'])*v*w+t['I']*w*w/2+G*abs(t['first_moment'])+d['pitch_friction_nm_assumed']
    yaw=(t['I']+turret+jy)*ay+abs(t['I_prime'])*v*w+t['I']*w*w+d['yaw_friction_nm_assumed']
    guide=guide_bound(extension,envelope,p=p)
    radius=g['extension_belt_pitch_m']*g['extension_pulley_teeth']/(2*math.pi)
    axial=(t['slider_mass']+5e-6/radius**2)*ae+abs(t['I_prime'])*w*w+t['slider_mass']*G
    extension_force=axial+guide['friction_n']
    return dict(peak_pitch_bound_nm=pitch,peak_yaw_bound_nm=yaw,
                I_dot_pitch_coupling_bound_nm=abs(t['I_prime'])*v*w,
                extension_force_bound_n=extension_force,guide_motion_bound=guide,
                pitch_motor=motor_demand_curve(pitch,w,d['pitch_ratio'],d['belt_efficiency']),
                yaw_motor=motor_demand_curve(yaw,w,d['yaw_ratio'],d['belt_efficiency']),
                extension_motor=motor_demand_curve(extension_force*radius,v/radius,1,d['belt_efficiency']))


def bom_totals(path=None):
    path=path or ROOT/'bom.csv'
    with path.open(newline='',encoding='utf-8-sig') as handle:
        rows=list(csv.DictReader(handle))
    errors=[]
    groups={}
    for row in rows:
        subtotal=int(row['qty'])*float(row['unit_price_usd'])
        if not math.isclose(subtotal,float(row['ext_price_usd']),abs_tol=0.005):
            errors.append(row['item'])
        groups[row['stage']]=groups.get(row['stage'],0)+subtotal
    subtotal=sum(groups.values())
    # This is an allowance, not a jurisdiction tax calculation or shipping quote.
    shipping_tax_allowance=round(0.12*subtotal,2)
    reserve=round(0.15*(subtotal+shipping_tax_allowance),2)
    return dict(purchase_subtotal_usd=round(subtotal,2),groups_usd={k:round(v,2) for k,v in groups.items()},
                shipping_tax_allowance_usd=round(shipping_tax_allowance,2),reserve_usd=round(reserve,2),
                cash_budget_usd=round(subtotal+shipping_tax_allowance+reserve,2),line_math_errors=errors,
                within_500_usd=subtotal+shipping_tax_allowance+reserve<=500)
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

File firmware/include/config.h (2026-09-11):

#ifndef CONFIG_H
#define CONFIG_H

#include <stdint.h>

#define CONTROL_HZ           1000
#define NUM_AXES             3

#define AXIS_YAW             0
#define AXIS_PITCH           1
#define AXIS_EXT             2

/* Soft limits (milli-deg or mm) */
#define YAW_MIN_MDEG         (-70000)
#define YAW_MAX_MDEG         (70000)
#define PITCH_MIN_MDEG       (-15000)
#define PITCH_MAX_MDEG       (70000)
#define EXT_MIN_MM           0
#define EXT_MAX_MM           500

/* Unqualified commissioning envelope; never a validated performance rating. */
#define YAW_VEL_CAP_MDEG_S   20000
#define PITCH_VEL_CAP_MDEG_S 20000
#define EXT_VEL_CAP_MM_S     150

#define WATCHDOG_MS          2
#define FRAME_TIMEOUT_MS      20
#define SETPOINT_TIMEOUT_MS   50
#define HOST_TIMEOUT_MS      200

#define PIN_ESTOP_SENSE      2
#define PIN_EXT_HOME         3
#define PIN_EXT_MAX          4
#define PIN_CATCH_SENSOR     5
#define PIN_LATCH_SERVO      6

#endif

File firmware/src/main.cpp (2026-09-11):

/**
 * Qualification firmware: protocol and safety diagnostics ONLY.
 * No command can enable motion until tested hardware adapters replace the lock.
 * Build may be flashed on a logic-only bench by a human; this is not motion firmware.
 */
#include "config.h"
#include "control_loop.h"
#include "protocol.h"
#include "command_receiver.h"
#include "safety.h"
#include "motors.h"
#include <string.h>
#if defined(ARDUINO)
#include <Arduino.h>
#else
#include <stdio.h>
struct FakeSerial {
  void begin(int) {}
  int available() { return 0; }
  int read() { return -1; }
  int availableForWrite() { return 128; }
  size_t write(const uint8_t *, size_t n) { return n; }
} Serial;
void pinMode(int, int) {}
int digitalRead(int) { return 1; }
#define INPUT_PULLUP 2
#define OUTPUT 1
unsigned long micros() { static uint32_t t=0; t+=1000; return t; }
unsigned long millis() { return micros()/1000; }
#endif

static CommandReceiver receiver;

static void publish_telemetry(uint32_t now_us) {
  TelemetryFrame t={};
  t.magic=PROTOCOL_MAGIC;t.version=PROTOCOL_VERSION;t.size=sizeof(t);
  t.timestamp_us=now_us;t.status=uint8_t(safety_state());
  t.catch_sensor=255; // unavailable until actual three-finger claw capture sensing exists
  t.yaw_mdeg=t.pitch_mdeg=t.extension_mm=INT32_MIN;
  t.yaw_vel_mdeg_s=t.pitch_vel_mdeg_s=t.ext_vel_mm_s=INT32_MIN;
  t.yaw_target_mdeg=control_axis(AXIS_YAW).target_valid ?
    int32_t(control_axis(AXIS_YAW).target*1000) : INT32_MIN;
  t.pitch_target_mdeg=control_axis(AXIS_PITCH).target_valid ?
    int32_t(control_axis(AXIS_PITCH).target*1000) : INT32_MIN;
  t.ext_target_mm=control_axis(AXIS_EXT).target_valid ?
    int32_t(control_axis(AXIS_EXT).target) : INT32_MIN;
  t.current_yaw_mA=t.current_pitch_mA=t.current_ext_mA=INT32_MIN;
  t.fault_bits=safety_faults();
  t.crc16=protocol_crc16(reinterpret_cast<const uint8_t*>(&t),sizeof(t)-2);
  Serial.write(reinterpret_cast<const uint8_t*>(&t),sizeof(t));
}

void setup() {
  motors_init();motors_disable_all(); // adapter stays unqualified; no imaginary output pins
  pinMode(PIN_ESTOP_SENSE,INPUT_PULLUP);
  pinMode(PIN_EXT_HOME,INPUT_PULLUP);
  pinMode(PIN_EXT_MAX,INPUT_PULLUP);
  pinMode(PIN_CATCH_SENSOR,INPUT_PULLUP);
  // Latch pin intentionally not configured: there is no qualified gripper adapter.
  safety_init();control_init();Serial.begin(921600);
}

void loop() {
  static bool started=false;
  static uint32_t last_us=0,last_tlm_ms=0;
  const uint32_t now_us=micros(),now_ms=millis();
  const uint32_t elapsed=now_us-last_us;
  if(started && elapsed<1000000u/CONTROL_HZ)return;
  if(started && elapsed>WATCHDOG_MS*1000u)safety_raise(FLT_WATCHDOG);
  started=true;last_us=now_us;
  // No catch-up burst after an overrun. Actual WCET/jitter still needs on-target measurement.
  SafetyInputs input;
  input.estop_open=digitalRead(PIN_ESTOP_SENSE)!=0;
  input.home_open=digitalRead(PIN_EXT_HOME)!=0;
  input.max_open=digitalRead(PIN_EXT_MAX)!=0;
  safety_tick(now_ms,input);
  for(unsigned budget=0;budget<128 && Serial.available()>0;++budget) {
    const int byte=Serial.read();
    if(byte<0)break;
    receiver.feed(uint8_t(byte),now_ms);
  }
  if(!safety_motion_allowed()) { motors_disable_all(); control_reset(); }
  // NO step generator, effort output, driver polling or gripper actuation is implemented.
  if(uint32_t(now_ms-last_tlm_ms)>=10 &&
      Serial.availableForWrite()>=int(sizeof(TelemetryFrame))) {
    last_tlm_ms=now_ms;publish_telemetry(now_us);
  }
}
#ifndef ARDUINO
int main(){setup();for(int i=0;i<3;++i)loop();printf("qualification firmware smoke ok; motion locked\n");return safety_motion_allowed()?1:0;}
#endif

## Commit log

2026-09-07 Initial commit: variable-reach dynamic catching arm.
    [BaseFootSpacer.stl, CableGuide.stl, CatcherAdapter.stl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]
2026-09-11 forgot to add free cad file and png
    [VariableReachArm_Full_RevB.FCStd]
